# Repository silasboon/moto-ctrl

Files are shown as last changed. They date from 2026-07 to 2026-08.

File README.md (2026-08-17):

# MOTO-CTRL

An open-source programmable motorcycle control board — an alternative to the
Motogadget m.Unit Blue. 12 switched outputs, 8 handlebar button inputs, BLE
phone-as-key immobilizer, and a companion mobile app, built around an
ESP32-S3. Open design, sold assembled by the project — Speeduino-style.

**MOTO-CTRL is feature-complete for its first release.** The firmware core,
BLE protocol, a WebSocket simulator with a browser debug GUI and QEMU boot
validation, the companion app (pairing, dashboard, output and button
configuration), the phone-as-key immobilizer, diagnostics (current sensing,
learnable fault thresholds, low-voltage cutoff), turn signals/hazard/brake
flasher with PWM dimming, and OTA firmware updates (signed images over BLE
with A/B partitions, a persisted security/safety event log, and a
forward-tolerant config format) are all implemented and covered by the
app's Firmware Update and Event Log screens and the maintainer
release-signing tool (`tools/sign-firmware.py`). Verified against the
simulator and host unit tests, and on real hardware: v1 boards exist, the
firmware runs on them, the app drives them over BLE, and the bench
checklist in [`docs/HARDWARE_TESTING.md`](docs/HARDWARE_TESTING.md) has
been worked through. See [`docs/PROTOCOL.md`](docs/PROTOCOL.md) for the
wire protocol, [`docs/TESTING.md`](docs/TESTING.md) for how all of this is
tested, and [`docs/WIRING.md`](docs/WIRING.md) /
[`docs/FLASHING.md`](docs/FLASHING.md) / [`docs/FAQ.md`](docs/FAQ.md) for
installing and flashing a board.

## Before anything else

- [`DISCLAIMER.md`](DISCLAIMER.md) — this is not a certified automotive
  safety device. Read it before wiring anything to a motorcycle.
- [`LICENSE-NOTE.md`](LICENSE-NOTE.md) — plain-English licensing summary
  (personal use/builds OK, selling boards or derivatives is not).
- Contributing? See [`CONTRIBUTING.md`](CONTRIBUTING.md) for the ground
  rules before opening a PR.

## Repository layout

```
moto-ctrl/
├── firmware/          ESP-IDF (C, FreeRTOS, NimBLE) firmware + host simulator
├── app/                bare React Native + TypeScript companion app
├── hardware/           schematic, PCB design, gerbers, BOM (per hardware revision)
│   ├── PINOUT.md        firmware ↔ hardware pin contract — read before touching pins
│   └── releases/         e.g. releases/v1/, matching git tags
├── enclosure/          STL/STEP files (FDM ASA prototype, MJF PA12 production)
├── docs/               wiring guide, flashing guide, protocol spec, FAQ, hardware bench checklist
├── tools/              version bump, OTA release signing, native app bootstrap
├── Makefile            build / test / release automation (make help)
└── .github/workflows/  CI: firmware build, app build, tests
```

## Building and testing

Everything except an on-target firmware build works with no hardware and no
ESP-IDF toolchain — the host simulator stands in for the board.

```sh
make test          # host ctest + sim integration tests + app typecheck/lint/jest
make help          # all targets
```

To work on the firmware and drive it by hand, build the host simulator and
open the browser debug console against it:

```sh
cd firmware/sim
cmake -S . -B build && cmake --build build
./build/moto_ctrl_sim 8010          # ws://127.0.0.1:8010
```

Then open `firmware/sim/gui/index.html` in a browser and click Connect —
live output state, per-channel current/faults, virtual handlebar buttons,
fault injection, and scenario record/replay. This is the primary day-to-day
development tool; see [`docs/TESTING.md`](docs/TESTING.md).

Building the real firmware needs the ESP-IDF toolchain
([`firmware/README.md`](firmware/README.md)); running the app on a device
needs Xcode or the Android SDK ([`app/NATIVE_SETUP.md`](app/NATIVE_SETUP.md)).
Flashing is UART0-only with a manual BOOT/EN sequence — see
[`docs/FLASHING.md`](docs/FLASHING.md).

Firmware releases are signed: `make release v=X.Y.Z` bumps the version,
builds, and signs a `.mcota` bundle; `make publish v=X.Y.Z` also tags and
creates the GitHub Release the app's update check reads. The signing key
lives outside this repo — see [`tools/README.md`](tools/README.md).

## Hardware

MCU: ESP32-S3-WROOM-1-N4 (4MB flash, no PSRAM), BLE 5. 12 outputs via 6×
Infineon BTS7008-2EPA high-side PROFETs with current sense and diagnostics.
8 active-low handlebar button inputs. 12V motorcycle power, LiFePO4-compatible.
UART0-only programming (no USB). See [`hardware/PINOUT.md`](hardware/PINOUT.md)
for the full pin contract.

## Software stack

- **Firmware:** ESP-IDF + NimBLE, C, FreeRTOS. A host simulator
  (`firmware/sim/`) builds the core state machine and protocol on
  Linux/macOS against a fake BLE transport, so the app and CI don't need
  real hardware.
- **App:** bare React Native + TypeScript (no Expo), BLE via
  `react-native-ble-plx`. Offline-first, zero cloud dependency, no accounts.

## Safety-critical behavior

MOTO-CTRL switches lighting, signaling, ignition, and starter circuits on a
moving vehicle. A handful of safety rules override every feature request
and are not up for debate in a PR: a BLE disconnect, app crash, or phone
absence never changes output state; the immobilizer can only lock while
the bike is stopped and off; every configured unlock method works at once,
and at least one non-phone method — the button cheat-code or an
ignition-switch input — must be configured before the immobilizer can be
enabled, so a dead phone can't strand you; phone-as-key uses bonded,
cryptographically signed challenge-response, never a bare MAC
address; the brake light is always on whenever the brake is pulled,
attention-flash pattern or not; the starter is never remotely triggerable
and is inhibited while the engine is already running; and low-battery
protection never disables the unlock path. See
[`CONTRIBUTING.md`](CONTRIBUTING.md) before proposing a change to lock,
output, or auth behavior, and [`DISCLAIMER.md`](DISCLAIMER.md) for what
this does and doesn't mean for your own liability.

## License

- Code (`firmware/`, `app/`, `tools/`): [PolyForm Noncommercial 1.0.0](LICENSE-CODE)
- Hardware & docs (`hardware/`, `enclosure/`, `docs/`): [CC BY-NC-SA 4.0](LICENSE-HARDWARE)
- Summary: [`LICENSE-NOTE.md`](LICENSE-NOTE.md)

## Contributing

See [`CONTRIBUTING.md`](CONTRIBUTING.md).

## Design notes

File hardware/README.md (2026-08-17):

# hardware/

Hardware design sources for MOTO-CTRL, licensed under CC BY-NC-SA 4.0 (see
[`../LICENSE-HARDWARE`](../LICENSE-HARDWARE) and
[`../LICENSE-NOTE.md`](../LICENSE-NOTE.md)).

- [`PINOUT.md`](PINOUT.md) — the firmware ↔ hardware contract: every GPIO
  assignment on the current board revision. This is the single source of
  truth firmware pin definitions must be generated from (see
  [`../CONTRIBUTING.md`](../CONTRIBUTING.md)).
- `releases/<rev>/` — per-hardware-revision design exports (EasyEDA Pro
  project source — `.epro`/`.epro2` depending on version, from `File ->
  Save As -> Save As (Local)`, which archives schematic + PCB + the device
  libraries and footprints actually used, whether the project itself lives
  in EasyEDA's cloud or locally — plus schematic PDF, `gerbers/`, `bom/`,
  `pnp/`), tagged in git to match the revision. `PINOUT.md` documents the
  current/latest revision; each `releases/<rev>/` snapshot is what actually
  shipped for that revision.

## Revisions

| Revision | Status | Notes |
|---|---|---|
| v1 ("Integrated V2") | current | First released hardware revision — "Integrated V2" is the schematic's own internal board name, from before this was a public project; the repo's revision numbering starts fresh at v1. See `PINOUT.md`, dated 2026-07-18. Design files are in [`releases/v1/`](releases/v1/). |

Only one PROFET may have DEN high at a time, GPIO3/GPIO46 are strapping
pins used safely by design (see `PINOUT.md`'s warning) — if you're revising
the hardware, re-read `PINOUT.md` in full before changing pin assignments,
since firmware depends on it directly.

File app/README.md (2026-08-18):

# app/

MOTO-CTRL companion app — bare React Native + TypeScript (no Expo), offline
first, zero cloud dependency, no accounts (see
[`CONTRIBUTING.md`](../CONTRIBUTING.md) for the full rule and its one
narrow exception). BLE/key logic must go through the `Transport` interface.

## Layout

- `src/transport/` — the `Transport` interface (channel-aware: `send`/
  `onMessage` take the logical channel explicitly, since BLE and the
  WebSocket sim frame it differently — see `docs/PROTOCOL.md` §1) and its
  two implementations:
  - `SimTransport` — talks to `firmware/sim/` over WebSocket. Used for all
    local dev and CI, so neither needs a board attached.
  - `BlePlxTransport` — real hardware, via `react-native-ble-plx`. Verified
    against a v1 board; re-check it per release with
    `docs/HARDWARE_TESTING.md`.
- `src/protocol/` — the real wire protocol (`docs/PROTOCOL.md`), transport-
  agnostic: `constants.ts` (opcodes/channels, mirrors `mc_protocol.h` by
  hand — deliberately excludes the simulator-only debug channel), `frames.ts`
  (byte/base64/utf8 helpers), `types.ts` (status + config JSON shapes), and
  `MotoClient.ts` — the high-level async client (auth, status polling,
  commands, config read/write) everything else is built on.
- `src/identity/KeyStore.ts` — persists this phone's Ed25519 identity
  (AsyncStorage, not platform secure storage — see the file's own header
  comment for why and `docs/TESTING.md` for when that might change) and the
  last-paired device.
- `src/update/updateCheck.ts` — the app's one permitted network call
  (fetching/verifying a firmware update manifest and bundle — see
  `docs/PROTOCOL.md` §10.5 and `CONTRIBUTING.md`'s "No cloud, no telemetry,
  no accounts" section), kept in its own module deliberately separate from
  `src/protocol/` (BLE/simulator wire protocol only).
- `src/screens/` — `PairingScreen` finds and authenticates a board.
  `DashboardScreen` ("Ride") is the landing screen: status, output control,
  a quick lock/unlock action, a battery/fault/low-voltage-cutoff indicator,
  and a Hazard button. Everything else sits one tap away behind
  `SettingsScreen`, the hub reached from Ride's settings button:
  - `OutputsScreen` — name each of the 12 channels, pick its behaviour
    (toggle, momentary, blink, flasher) and PWM dimming, and set the role
    flags that carry real firmware behaviour (`essential`, `is_ignition`,
    `is_starter`, `is_brake`).
  - `ButtonsScreen` — name the 8 inputs and bind single/double/hold presses
    and chords to output channels or turn/hazard actions, with an
    identify-by-pressing flow (`INPUT_LEARN`).
  - `BoardScreen` — settings about the board itself (currently its name).
  - `KeysScreen`, `LockScreen` (immobilizer enable/methods, cheat-code
    set/clear/test, ownership transfer).
  - `DiagnosticsScreen` — live per-channel current + fault, learnable
    open-load/overcurrent thresholds, low-voltage-cutoff and
    engine-running voltage config, board calibration, and a live BLE
    signal-strength (RSSI) readout — phone-side, read straight from the
    radio via `Transport.readRssi()`, for bench-testing how far phone-as-key
    reaches with the board mounted on the bike. Advisory only: nothing in
    the unlock path reads this value.
  - `FirmwareUpdateScreen` (checks for/downloads/transfers a signed OTA
    update, then applies it on request), `EventLogScreen` (read-only viewer
    for the device's persisted security/safety event log), and
    `BoardInfoCard` (firmware version + uptime, shown atop Settings).

  Screens are switched via local state in `App.tsx` — no navigation library
  (see `App.tsx`'s header comment for why). Leaving a screen with unsaved
  edits routes through `src/ui/NavGuard.tsx`, so an edge-swipe back gets the
  same confirmation the screen's own Back chevron does.
- `ios/`, `android/` — the committed bare-RN native projects (bundle ID
  `com.motoctrl.app`, BLE permissions configured). See
  [`NATIVE_SETUP.md`](NATIVE_SETUP.md) to build or regenerate them.

## Status

Pairing, dashboard, output and button configuration, the lock/immobilizer
screen, diagnostics, turn-signal/hazard/brake-flasher/PWM control, firmware
updates, and the event log viewer are all implemented against
`SimTransport` and verified against a real `firmware/sim/` instance (see
Testing below), and `BlePlxTransport` has been exercised against a real
board over BLE.

The cheat-code is write-only from the app's perspective by design — the
device only ever reports whether one is set and how long it is (never the
sequence, never a hash); physical entry happens on the handlebar buttons,
not through this app.

Diagnostics thresholds/cutoff config go through dedicated `DIAG_GET_CONFIG`/
`DIAG_SET_CONFIG` wire ops (same pattern as lock config), not the generic
config JSON, even though they also ride it for export/import completeness
(`DeviceConfig.diagnostics`) — `DiagnosticsScreen` edits live values through
the dedicated ops. Board calibration is a separate, even-less-often-touched
set of ops (`DIAG_GET_CALIB`/`DIAG_SET_CALIB`) that never rides a config
export/import or gets cleared by ownership transfer, since it describes the
physical board, not the owner.

Flasher/PWM config (behaviour, duty, auto-cancel/blink/pulse timing,
brake-switch input) is different from both of the above: it rides the
generic config JSON exclusively (`OutputsScreen`, alongside name and role
flags — output config never had its own dedicated wire channel, unlike
lock/diagnostics). The one dedicated opcode here is `hazardPress()` — a
plain turn-signal toggle is still just `setOutput()` on a channel whose
`indicator` is set to left or right; mutual exclusion and the auto-cancel
timer are applied device-side, not by this app.

Known MVP simplifications, not gaps in a safety requirement:

- Enrolling a second phone is done by pasting its base64 public key (shown
  on its own Pairing screen) into the first phone's Keys screen — no QR/
  camera flow, to avoid pulling in a camera dependency for a one-off step.
- The phone's private key lives in AsyncStorage, not the iOS Keychain /
  Android Keystore — a deliberate initial simplification, not yet
  revisited.
- `MotoClient` polls status on an interval rather than relying on
  device-pushed notifications: real firmware only replies to an explicit
  `STATUS_GET` today (unlike the simulator's dev-convenience ticker).
- **Background BLE reconnect** (`src/ble/BoardSession.ts`) is what lets
  phone-as-key reconnect and unlock without the app open. It's a single
  always-running watch/connect/retry state machine, started unconditionally
  at boot (`index.js`, before `AppRegistry.registerComponent`) rather than
  from any screen, so it's already running by the time a background-relaunch
  needs it. `src/ble/bleManager.ts` constructs the shared `BleManager` with
  `restoreStateIdentifier`/`restoreStateFunction` (iOS CoreBluetooth state
  restoration; `UIBackgroundModes` → `bluetooth-central` in Info.plist is
  the corresponding capability declaration) so a fully-terminated app can
  pick a reconnecting peripheral back up. `src/ble/nativeBleWatchService.ts`
  bridges to `BleWatchService` (Android-only native module,
  `android/app/src/main/java/com/motoctrl/app/ble/`) — a foreground service
  with a persistent low-priority notification, since Android freezes or
  kills a backgrounded process with no foreground service, which would
  otherwise silently stop the watcher. `PairingScreen`'s own scan/tap flow
  still exists for pairing a new board or an impatient manual reconnect
  (`BoardSession.connectManually()`, sharing an in-flight guard with the
  watcher so the two can never race a double-connect); App.tsx subscribes to
  `BoardSession` directly rather than owning connection state itself.
  Compiles and typechecks clean on both platforms (`./gradlew assembleDebug`,
  `xcodebuild … -sdk iphonesimulator`) and the state machine has unit
  coverage (`src/__tests__/BoardSession.test.ts`), but **has not been
  bench-verified on real hardware** — background reconnect is exactly the
  kind of behavior that only really proves itself on a physical phone across
  a real suspend/kill/relaunch cycle. See `docs/HARDWARE_TESTING.md` §7.

## Development

```sh
npm install
npm run typecheck
npm run lint
npm test
```

`npm test` includes a live integration suite
(`src/__tests__/sim.itest.test.js`) that spawns a real `firmware/sim/`
instance and drives it through `SimTransport` + `MotoClient` — build the sim
first, or it skips gracefully:

```sh
cd ../firmware/sim && cmake -S . -B build && cmake --build build
```

Running on a device (`npm run ios` / `npm run android`) needs Xcode or the
Android SDK — see [`NATIVE_SETUP.md`](NATIVE_SETUP.md). BLE needs a physical
device; it does not work on the iOS Simulator or a stock Android emulator.

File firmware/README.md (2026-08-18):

# firmware/

ESP-IDF (C, FreeRTOS, NimBLE) firmware for the MOTO-CTRL board
(ESP32-S3-WROOM-1-N4). See [`CONTRIBUTING.md`](../CONTRIBUTING.md) for the
safety requirements and pin-config rule that govern everything in this
directory, and [`hardware/PINOUT.md`](../hardware/PINOUT.md) for the pin
contract.

## Layout

- `components/core/` — the portable core: state machines + protocol + auth,
  plain C99 with no ESP-IDF/FreeRTOS dependency, built by both the on-target
  component and `sim/` from the same sources.
  - `mc_output` (12-channel output engine; on/off, PWM dimming, and
    turn/brake flasher patterns — see below), `mc_input`
    (debounce, short/long/double press, chord + sequence combos),
    `mc_config` (versioned config blob + migration), `mc_persist`
    (debounced-write scheduler for NVS wear), `mc_power` (parked/idle power
    policy — decides tick rate, light sleep and advertising class).
  - `mc_crypto` (Ed25519 verify/sign + CSPRNG), `mc_keystore` (enrolled
    public keys), `mc_status` (status snapshot), `mc_config_json`
    (config ↔ JSON), `mc_session` (the transport-agnostic protocol + auth
    engine), `mc_protocol.h` (wire constants).
  - `vendor/` — TweetNaCl (Ed25519, public domain) + cJSON (MIT), unmodified.
- `components/board_config/` — the single source of GPIO pin definitions,
  generated from `hardware/PINOUT.md`, plus `board_config_early_init()`
  (GPIO3/GPIO46 strapping-pin safety). No other file may hardcode a GPIO
  number.
- `main/` — `app_main` and the ESP-IDF-specific glue: GPIO HALs
  (`output_hal_gpio` — plain digital plus lazily-attached LEDC PWM for
  opt-in dimming; `input_hal_gpio`), the current-sense/battery ADC HAL
  (`diag_hal` — DSEL/DEN mux sequencing, `hardware/PINOUT.md`), NVS stores
  (`nvs_config_hal`, `nvs_keystore_hal`,
  `nvs_lock_hal`, `nvs_calib_hal`), the physical factory-reset flow
  (`factory_reset.c`, BOOT-hold), `power_hal` (applies `mc_power`'s profile
  via `esp_pm` locks), `watchdog`, and `ble/` — the NimBLE GATT
  server (`gatt_svr.c`), LE Secure Connections bonding + advertising
  (`ble_app.c`), and UUIDs (`ble_uuids.h`), all wiring the BLE transport to
  `mc_session`.
- `sim/` — a standalone host (Linux/macOS) CMake project that builds
  `components/core/` behind a self-contained WebSocket "fake BLE" server
  (`src/ws_server.c`), plus C unit tests (`sim/tests/`) and Node integration
  tests (`sim/itest/`), so the app and CI run with no hardware. Independent
  of the ESP-IDF build.
  - `sim/src/sim_debug.c` + `sim_nvs.c` + `sim_protocol.h` — the sim-only
    debug/fault-injection channel (fake battery/current/fault, forced
    disconnect/reboot/NVS-corruption, event log) and fake NVS blob store
    that back it. Never part of the real protocol — see `docs/TESTING.md`.
  - `sim/gui/` — a static browser debug console (`index.html`/`app.js`, no
    build step) that drives the sim over WebSocket: live output state +
    real per-channel current/fault, a Hazard button, virtual buttons,
    auth/key management, lock/immobilizer config, diagnostics
    thresholds/calibration, config read/write (mode/duty/flasher-timing
    editing lives here, not as dedicated Outputs-panel widgets — see
    docs/TESTING.md), OTA transfer controls, an event log viewer, and
    scenario record/replay. The primary day-to-day dev tool for the app and
    firmware alike.
- `partitions.csv` / `sdkconfig.defaults` — 4MB flash, OTA A/B partitions
  with rollback, NimBLE-only Bluetooth (bonds persisted to NVS), no PSRAM,
  no WiFi, and the power-management options `mc_power` depends on (DFS +
  automatic light sleep, BLE controller modem sleep on the main crystal).

## Building the firmware (on-target)

Requires the [ESP-IDF](https://docs.espressif.com/projects/esp-idf/en/stable/esp32s3/get-started/index.html)
toolchain (latest stable), targeting `esp32s3`:

```sh
. $IDF_PATH/export.sh
cd firmware
idf.py set-target esp32s3
idf.py build
```

Flashing uses UART0 only (3-pin TX/RX/GND header, no USB, no auto-reset) —
see [`docs/FLASHING.md`](../docs/FLASHING.md) for the manual BOOT/EN sequence.

## Building the host simulator

No ESP-IDF toolchain required — just CMake and a C compiler:

```sh
cd firmware/sim
cmake -S . -B build
cmake --build build
ctest --test-dir build            # C unit tests

# Integration tests (WebSocket protocol + C<->JS Ed25519 interop) need Node:
cd itest && npm ci && MOTO_SIM_BIN=../build/moto_ctrl_sim npm test
```

Run the simulator standalone for app/GUI development (default port 8010):

```sh
./firmware/sim/build/moto_ctrl_sim 8010   # ws://127.0.0.1:8010
```

Then open `firmware/sim/gui/index.html` in a browser and click Connect. See
[`docs/TESTING.md`](../docs/TESTING.md) for the full harness (debug
protocol, scenario record/replay, QEMU boot validation).

## Building under QEMU (boot validation only — not BLE)

```sh
. $IDF_PATH/export.sh
cd firmware
idf.py set-target esp32s3 && idf.py build
python "$IDF_PATH/tools/idf_tools.py" install qemu-xtensa
timeout 30 idf.py qemu
```

Validates boot sequence, NVS/config load, output restore, and watchdog init
on the real binary. Does **not** validate BLE — see
[`docs/TESTING.md`](../docs/TESTING.md) §5 before drawing any conclusion
about pairing/bonding/auth from a QEMU run.

## Status

The full feature set is implemented and tested:

- **BLE stack.** The transport-agnostic protocol + auth engine
  (`mc_session`): status, control, and config (chunked JSON) channels, with
  all state-changing operations gated behind an Ed25519 challenge-response
  (`mc_crypto` + `mc_keystore`). The device stores only public keys; nonces
  are single-use. NimBLE GATT server with LE Secure Connections bonding
  (bonds in NVS), advertising as `MOTO-CTRL`, per-connection sessions.
- **Pre-hardware validation harness.** A real `mc_input` engine runs inside
  the sim (10ms tick); a fake NVS blob store makes config/keystore/lock/
  calibration persistence — and its corruption — real and reloadable via a
  simulated reboot; the sim-only debug channel + browser GUI (`sim/gui/`);
  and QEMU boot validation, which boots the real cross-compiled binary and
  checks its boot-sequence log markers. QEMU is a local-only step — it is
  **not** part of CI, and it does not and cannot validate BLE. See
  `docs/TESTING.md` §5 before drawing conclusions from it.
- **Lock / immobilizer** (`mc_lock`, `docs/PROTOCOL.md` §11): the
  four-state FSM (DISABLED/UNLOCKED/PARKED/LOCKED), edge-triggered
  phone-as-key auto-unlock, a salted-hash button cheat-code with
  progressive wrong-entry backoff, ignition-switch mode, ownership
  transfer, and the physical BOOT-hold factory reset (`factory_reset.c`).
- **Diagnostics** (`mc_diag`, `docs/PROTOCOL.md` §12): round-robin
  per-channel current sensing over the shared PROFET IS line
  (`hardware/PINOUT.md`) with learnable open-load/overcurrent thresholds;
  `engine_running`, feeding the starter-protection and lock
  parked-detection guards — an unconditional ignition-off override (an
  assigned ignition channel that's off always means not-running) plus
  opt-in, off-by-default voltage-based detection (never assumed, since a
  booster pack looks identical to a running alternator); a low-voltage
  battery cutoff that
  suppresses non-essential outputs (`CONTRIBUTING.md` safety requirement
  #7) while leaving commanded/intent state untouched; and board calibration
  in its own NVS blob, excluded from config export/import and from factory
  reset (it describes the board, not the owner).
- **Flashers / PWM** (`mc_output`, `docs/PROTOCOL.md` §13): turn signals
  and hazard, with mutual exclusion and an auto-cancel timer embedded
  directly in `mc_output_set()` (so any caller — a handlebar button, or the
  `HAZARD_PRESS` wire op — gets correct behavior for free), a brake-flasher
  attention-pulse burst (opt-in, off by default per `CONTRIBUTING.md`
  safety requirement #5), and opt-in per-channel PWM dimming
  (lazily-attached LEDC on real hardware). Handlebar buttons bind to
  actions besides the cheat-code — each of `short_press_action[]`,
  `long_press_action[]` and `double_press_action[]` holds a per-button LIST
  of actions (turn-L/turn-R toggle, hazard press, or `256 + N` to toggle
  output channel N directly) — and a physical brake-lever/pedal switch input
  (`brake_switch_input`, read as a level, mirrors
  `starter_interlock_input`).
- **OTA + config migration + event log** (`mc_ota`, `mc_event_log`,
  `docs/PROTOCOL.md` §10/§15): signed firmware updates over BLE (A/B
  partitions, Ed25519 signature over a streamed SHA-512 digest so no PSRAM
  buffering is needed, safe-state gating on `engine_running`/low-voltage
  cutoff at both begin and reboot time) and a persisted, fixed-size ring
  buffer of security/safety events (lock transitions, key enroll/revoke/
  transfer, factory reset, cheat-code lockout, OTA begin/success/failure,
  low-voltage cutoff), readable over its own chunked wire op. Config
  migration needed no new code: `mc_config_json`'s already-tolerant parsing
  (missing fields default, unknown fields ignored) handles an older or
  newer-but-understood document without a separate binary migration path —
  only a future schema version this firmware doesn't understand is
  rejected outright. `tools/sign-firmware.py` generates the release keypair
  and signs images into `.mcota` bundles; the app has a Firmware Update
  screen and an Event Log viewer.
- Protocol spec: [`docs/PROTOCOL.md`](../docs/PROTOCOL.md).

Verified: host `ctest` (12 suites, including `test_ota.c`/
`test_event_log.c`), the Node integration suite (33 cases against a real
spawned sim, including a full signed OTA transfer, safe-state-gating
rejection, and event log read/since_seq coverage), and the app's own Jest
suite (116 cases across 11 files) — all pass. Beyond that, the firmware has
been built for the real `esp32s3` target, flashed to a board, and driven
over BLE from the app, and the bench checklist in
[`../docs/HARDWARE_TESTING.md`](../docs/HARDWARE_TESTING.md) has been worked
through against real hardware. Re-run that checklist per release rather than
treating it as settled — it is the only layer that covers real GPIO, real
current sensing, and real BLE.

**Parked power management** (`mc_power`, `power_hal`). The portable policy
picks one of three levels from the live device state — ACTIVE (10ms tick, no
sleep), IDLE (100ms, light sleep allowed), PARKED (250ms, light sleep, slow
BLE advertising) — and `power_hal` applies it via `esp_pm` locks and the
advertising interval. Light sleep rather than deep sleep is forced by the
hardware: deep-sleep GPIO wake needs an RTC-capable pin and BTN1-8 are on
GPIO35-42, outside the ESP32-S3's RTC domain (GPIO0-21). Light sleep also
keeps the radio up, so phone-as-key stays live on a parked bike. Buttons
wake the loop through a GPIO interrupt that notifies `app_task`, with the
250ms parked tick as a backstop if that notify is ever missed. Every
hold-awake gate (outputs driven, engine running, ignition live, OTA in
flight, a gesture in progress, factory-reset window open) pins ACTIVE and
refuses sleep — `test_power.c` covers each one. Not yet measured on a
bench: `docs/HARDWARE_TESTING.md` §1 is where the number gets recorded.

Two implementation notes worth knowing about:

- `firmware/sdkconfig.defaults` enables
  `CONFIG_BOOTLOADER_APP_ROLLBACK_ENABLE`, so every OTA-updated image boots
  in "pending verify" state and the bootloader would revert on the *next*
  reset unless the image confirms itself. `app_main()` calls
  `esp_ota_mark_app_valid_cancel_rollback()` as its last step, once every
  boot stage (config/output/lock restore, diagnostics, input, watchdog,
  BLE) has completed without crashing — see the comment at that call site,
  and `docs/HARDWARE_TESTING.md` §11 for the reset-after-OTA check.
- The physical factory reset is a 5-second arming window watched on the app
  tick (`factory_reset_init()` / `factory_reset_tick()`), not a sample at
  boot: holding BOOT through reset enters UART download mode, because BOOT
  is GPIO0 and its level at the strap instant selects the boot path, so
  `app_main()` would never run. The gesture is "apply power, then press and
  hold BOOT" — see `firmware/main/factory_reset.h`, `docs/FLASHING.md`'s
  Factory reset section, and `docs/HARDWARE_TESTING.md` §9.

The generic `combos[]` chord/sequence mechanism dispatches its own
`actions` list, orthogonal to the lock cheat-code and to the per-button
press bindings, which all consume short-press events independently of the
combo matcher. A matched *chord* additionally marks its member buttons so
their own bindings don't also fire (the press event is still delivered,
flagged `action_suppressed`, so the cheat-code can never be starved — see
`mc_input.h`). A matched *sequence* suppresses nothing, since its member
presses were already delivered before it completed.

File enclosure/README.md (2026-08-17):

# enclosure/

Enclosure design files for MOTO-CTRL, licensed under CC BY-NC-SA 4.0 (see
[`../LICENSE-HARDWARE`](../LICENSE-HARDWARE)).

- FDM ASA — prototype/hobbyist printing.
- MJF PA12 — production.

Two printed parts per revision — a base and a separate lid:

```
enclosure/
└── v1/
    ├── moto-ctrl-enclosure-v1.step   # base, source/editable
    ├── moto-ctrl-enclosure-v1.stl    # base, print-ready
    ├── moto-ctrl-lid-v1.step         # lid, source/editable
    └── moto-ctrl-lid-v1.stl          # lid, print-ready
```

Per-revision print settings and material notes (layer height, walls,
infill, orientation, supports, and what differs between the ASA prototype
and the MJF production part) are **not written up yet** — print the STLs
with sensible ASA defaults until they are.

Enclosure revisions should track hardware revisions in `hardware/releases/`
— an enclosure for board rev v1 assumes the connector/mounting layout of
`hardware/releases/v1/`.

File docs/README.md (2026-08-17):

# docs/

User- and protocol-facing documentation, licensed under CC BY-NC-SA 4.0 (see
[`../LICENSE-HARDWARE`](../LICENSE-HARDWARE)).

| Doc | Content |
|-----|---|
| [`PROTOCOL.md`](PROTOCOL.md) | BLE GATT layout: status/control/config/lock/diagnostics/flashers/OTA/event-log services + auth, documented for third-party clients |
| [`TESTING.md`](TESTING.md) | Test pyramid, sim debug GUI, sim-only debug protocol, scenario format, QEMU boot validation and its BLE-fidelity limits |
| [`WIRING.md`](WIRING.md) | Wiring guide for installing MOTO-CTRL on a motorcycle |
| [`FLASHING.md`](FLASHING.md) | UART0 flashing guide, manual BOOT/EN sequence (no USB, no auto-reset) |
| [`FAQ.md`](FAQ.md) | Frequently asked questions |
| [`HARDWARE_TESTING.md`](HARDWARE_TESTING.md) | Bench validation checklist — worked through on v1 hardware; re-run per release |

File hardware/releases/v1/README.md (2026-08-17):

# hardware/releases/v1/

Design export for hardware revision v1 ("Integrated V2" on the schematic
itself — that name predates this being a public project; the repo's own
revision numbering starts at v1) — the revision documented in
[`../../PINOUT.md`](../../PINOUT.md).

```
v1/
├── schematic.pdf
├── moto-ctrl-v1.epro2      # EasyEDA Pro project export (source) --
│                           # File -> Save As -> Save As (Local)
├── gerbers/                # Gerber RS-274X + Excellon drill, JLCPCB naming
├── bom/
└── pnp/
```

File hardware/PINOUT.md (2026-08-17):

# MOTO-CTRL Hardware Pinout — Board "Integrated V2" (schematic 2026-07-18)

This file is the firmware ↔ hardware contract. All pin definitions in firmware must
come from a single board-config header generated from this table. Source of truth:
`hardware/releases/v1/` schematic.

MCU: ESP32-S3-WROOM-1-N4. UART0 programming only (no USB — IO19/IO20 are
intentionally unconnected). Manual boot entry: hold BOOT (SW2, IO0) and pulse
RESET (SW1, EN).

## PROFET control (6× BTS7008-2EPA, U2–U7)

Each PROFET has two channels: IN0 → OUTx (odd), IN1 → OUTy (even).
All PROFET logic lines go through 4.7kΩ series resistors.

| Device | Signal | ESP32 GPIO | Drives |
|---|---|---|---|
| U2 | PROFET_IN1  | GPIO47 | OUT1 |
| U2 | PROFET_IN2  | GPIO14 | OUT2 |
| U2 | PROFET_DEN1 | GPIO21 | U2 diag en  |
| U3 | PROFET_IN3  | GPIO13 | OUT3 |
| U3 | PROFET_IN4  | GPIO11 | OUT4 |
| U3 | PROFET_DEN2 | GPIO12 | U3 diag en  |
| U4 | PROFET_IN5  | GPIO10 | OUT5 |
| U4 | PROFET_IN6  | GPIO3  ⚠ | OUT6 |
| U4 | PROFET_DEN3 | GPIO46 ⚠ | U4 diag en  |
| U5 | PROFET_IN7  | GPIO8 | OUT7 |
| U5 | PROFET_IN8  | GPIO17 | OUT8 |
| U5 | PROFET_DEN4 | GPIO18 | U5 diag en  |
| U6 | PROFET_IN9  | GPIO16 | OUT9 |
| U6 | PROFET_IN10 | GPIO7 | OUT10 |
| U6 | PROFET_DEN5 | GPIO15 | U6 diag en  |
| U7 | PROFET_IN11 | GPIO6 | OUT11 |
| U7 | PROFET_IN12 | GPIO4 | OUT12 |
| U7 | PROFET_DEN6 | GPIO5 | U7 diag en  |

Shared diagnostic lines:

| Signal | ESP32 GPIO | Notes |
|---|---|---|
| PROFET_DSEL  | GPIO48 | Channel select for IS mux, shared across U2–U7 |
| PROFET_IS | GPIO9 | ADC1_CH8. Sense: 2kΩ (R3) to GND, RC 2.2kΩ/1nF |

⚠ Strapping pins: GPIO3 (JTAG source) and GPIO46 (ROM log) are used as outputs to
PROFET IN6/DEN3. Both are pulled inactive by the PROFET input structure at boot and
the assignment is verified safe on this hardware — but firmware must never enable
internal pullups on these two pins before boot completes, and must drive them low
during early init.

## Diagnostics readout procedure

Only one PROFET may have DEN high at a time. To read a channel current:
set DSEL (0 = OUT-odd/IN0 channel, 1 = OUT-even/IN1 channel), raise that device's
DENx, settle, read ADC on GPIO9, lower DENx. Round-robin all 12 channels.
I_load ≈ (V_IS / 2000Ω) × kILIS (see BTS7008-2EPA datasheet; calibrate per board).

## Handlebar buttons (via CN2)

Active-low. Each input: 2.2kΩ series + 10kΩ pullup to 3V3 + 10nF to GND.

| Signal | ESP32 GPIO |
|---|---|
| BTN1 | GPIO35 |
| BTN2 | GPIO36 |
| BTN3 | GPIO37 |
| BTN4 | GPIO38 |
| BTN5 | GPIO39 |
| BTN6 | GPIO40 |
| BTN7 | GPIO41 |
| BTN8 | GPIO42 |

## Analog

| Signal | ESP32 GPIO | ADC channel | Notes |
|---|---|---|---|
| VSENSE_BAT | GPIO1 | ADC1_CH0 | 1MΩ/100kΩ divider, ratio 0.0909. Use 12dB attenuation. Filter cap C5 100nF. Calibrate offset/gain per board. |
| PROFET_IS  | GPIO9 | ADC1_CH8 | See diagnostics section |

## System / programming

| Function | Pin | Notes |
|---|---|---|
| UART TX | TXD0 (GPIO43) | 3-pin header H1: 1=TX, 2=RX, 3=GND (3.3V logic, no auto-reset) |
| UART RX | RXD0 (GPIO44) | |
| BOOT | GPIO0 (SW2) | Also usable at runtime as the factory-reset button (hold at power-on) |
| RESET | EN (SW1) | 10kΩ pullup + 1µF |

## Reserved / unconnected

| Pin | Status |
|---|---|
| GPIO2  | Spare, ADC1-capable, routed to no net. Reserved: NTC board temp / 5V monitor / aux analog. No driver yet. |
| GPIO19 | NC (USB D-; USB intentionally unused) |
| GPIO20 | NC (USB D+) |
| GPIO45 | NC (strapping, VDD_SPI — correct to leave unconnected) |

## External connectors

CN1 (KF142V-5.08-12P, output terminal): pin N = OUTN for N = 1…12.
CN2 (KF142V-5.08-8P, button input terminal): reverse order — pin N = BTN(9−N).
  Pin 1 = BTN8, pin 2 = BTN7, pin 3 = BTN6, pin 4 = BTN5,
  pin 5 = BTN4, pin 6 = BTN3, pin 7 = BTN2, pin 8 = BTN1.
  (Verified by the board designer against the layout.)
Power: 4× M3 ring-terminal pads (U11–U14) — main +12V and GND, dual feed.
LEDs: LED1–LED12 mirror OUT1–OUT12 (2.2kΩ from each OUT rail); LED13 = 3V3 power
  indicator (4.7kΩ, R40).

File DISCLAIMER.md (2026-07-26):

# Disclaimer

MOTO-CTRL is an open-source hobbyist project. Read this before you build, flash,
wire, or ride with it.

## Not a certified automotive device

MOTO-CTRL has **not** been certified, homologated, or approved by any regulatory
body (no ISO 26262 functional-safety certification, no DOT/ECE/UNECE type
approval, no CE/FCC/UKCA compliance testing beyond whatever informal checks the
maintainer chooses to publish). It is not a product built to automotive
functional-safety standards. Do not treat it as one.

## You assume all risk

By designing, building, flashing, wiring, installing, configuring, or riding a
motorcycle equipped with MOTO-CTRL, you accept full responsibility for:

- Verifying the wiring, fusing, and installation are correct for your specific
  motorcycle before riding it.
- Confirming your installation complies with the vehicle regulations in your
  jurisdiction (lighting, signaling, and electrical codes vary by country and
  state/province — this project does not track them for you).
- Any damage to your motorcycle, its electrical system, or other property arising
  from use, misuse, or malfunction of this hardware or software.
- Any injury to yourself or others arising from use, misuse, or malfunction of
  this hardware or software, including but not limited to failure of lighting,
  signaling, starting, or immobilizer functions.
- Testing thoroughly on a bench and in a controlled, stationary setting before
  ever riding with a new configuration or firmware version.

## No warranty

THE SOFTWARE, HARDWARE DESIGNS, AND DOCUMENTATION ARE PROVIDED "AS IS", WITHOUT
WARRANTY OF ANY KIND, EXPRESS OR IMPLIED, INCLUDING BUT NOT LIMITED TO THE
WARRANTIES OF MERCHANTABILITY, FITNESS FOR A PARTICULAR PURPOSE, AND
NONINFRINGEMENT. IN NO EVENT SHALL THE AUTHORS, CONTRIBUTORS, OR THE MOTO-CTRL
PROJECT BE LIABLE FOR ANY CLAIM, DAMAGES, OR OTHER LIABILITY ARISING FROM,
OUT OF, OR IN CONNECTION WITH THE SOFTWARE, HARDWARE, OR THE USE OR OTHER
DEALINGS IN THEM — INCLUDING DAMAGE TO YOUR VEHICLE, PERSONAL INJURY, OR DEATH.
See the "No Liability" section of [`LICENSE-CODE`](LICENSE-CODE) and the
liability/warranty disclaimers in [`LICENSE-HARDWARE`](LICENSE-HARDWARE) for the
legally binding terms.

## Safety-critical wiring

MOTO-CTRL switches your motorcycle's lighting, signaling, ignition, and starter
circuits. A wiring mistake, a misconfigured output, or a firmware bug in a
modified fork can cause loss of lights, loss of signaling, an immobilized bike,
or unintended starter engagement. Always:

- Keep the stock ignition kill switch and any stock immobilizer functional and
  accessible as a fallback unless you fully understand what you are removing.
- Fuse every output appropriately for the connected load.
- Bench-test a new build (power, outputs, inputs) before installing it on the bike.
- Re-verify safety-critical behavior (lights, brake light, starter interlock)
  after every firmware update, on the bench, before riding.

## Project scope

This disclaimer applies to the MOTO-CTRL software (`firmware/`, `app/`), hardware
designs (`hardware/`, `enclosure/`), and documentation (`docs/`) in this
repository, and to any board — self-built or purchased assembled from the
MOTO-CTRL project — running this software or a derivative of it.

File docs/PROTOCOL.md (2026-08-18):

# MOTO-CTRL BLE Protocol

This document specifies the MOTO-CTRL wire protocol well enough for a
third-party client to be built. It is the authoritative companion to the
implementation in `firmware/components/core/` (`mc_protocol.h`,
`mc_session.c`) and the GATT definitions in `firmware/main/ble/`. If code and
this document ever disagree, that is a bug — please report it.

> **Status:** the status, control, config, lock/immobilizer (§11),
> diagnostics (§12), flashers/PWM (§13), OTA (§10), and event log (§15)
> services are all implemented.

## 1. Transports

The same logical protocol runs over two transports:

- **BLE GATT** (real hardware). Each *channel* below is a GATT
  characteristic. A client writes a frame to a characteristic and receives
  responses as notifications on the same characteristic.
- **WebSocket** (the `firmware/sim/` host simulator, for development and CI
  with no hardware). Each message is a single binary WebSocket frame whose
  **first byte is the channel id**, followed by the frame bytes. The
  simulator listens on `ws://127.0.0.1:<port>` (default `8010`).

A "frame" is identical on both transports:

```
frame = opcode:u8  payload:bytes
```

On BLE the channel is implied by which characteristic carried the frame; on
WebSocket the channel is the leading byte. Everything after that — opcode and
payload — is the same. A worked reference client is
`firmware/sim/itest/moto-client.mjs`.

Multi-byte integers are **little-endian** unless stated otherwise.

## 2. GATT layout

Base UUID: `5a4f00XX-9b1e-4f8a-9c2d-1a2b3c4d5e6f`, where `XX` selects the
service or characteristic.

| Service (UUID `XX`) | Characteristic (UUID `XX`) | Channel id | Properties |
|---|---|---|---|
| Status `0x10` | Status `0x11` | `0` | Read, Write, Notify |
| Control `0x20` | Auth `0x21` | `1` | Write, Notify |
| Control `0x20` | Command `0x22` | `2` | Write, Notify |
| Config `0x30` | Config `0x31` | `3` | Write, Notify |
| OTA `0x40` | OTA `0x41` | `4` | Write, Notify |

**Advertising layout.** The primary advertising payload carries the flags and
the **Status service UUID** (`5a4f0010-…`); the **name** is in the scan
response. Discover boards by that service UUID, never by name: the name is
rider-configurable (`device_name`, §9) and defaults to `MOTO-CTRL` only until
somebody changes it, so a name match finds only boards nobody has renamed.

The two were the other way round before `schema_version` 8. The UUID moved
into the primary payload so a scanner can filter on it reliably, and the name
moved out so it has the room a 128-bit UUID left it without (about 10 bytes
of the 31).

Clients that will read config **must** negotiate an ATT MTU large enough to
carry a config chunk frame (see §7): the 128-byte chunk payload plus a 4-byte
chunk header, opcode, and ATT overhead — request an MTU of at least ~185.

Clients that will perform an OTA update should negotiate the largest MTU the
stack supports (BLE 5's practical ceiling is 512 bytes of ATT payload) — a
larger MTU means fewer `OTA_CHUNK` round trips for the same image. There is
no minimum: `OTA_CHUNK` accepts any chunk size that fits one write, down to a
single byte, at the cost of more round trips.

## 3. Pairing and session model

1. **BLE bonding.** The client pairs using **LE Secure Connections**
   (Just Works; bonding enabled). This encrypts the link and persists a bond.
   Link/bond alone grants **no** authority — see below.
2. **Application-layer authentication.** Every connection starts an
   unauthenticated *session*. Until the session is authenticated via the
   challenge-response (§5), the device permits only: reading status (§4),
   `AUTH` operations (§5), and *first-key* enrollment (§6). All
   state-changing operations (control, config write) are refused with
   `UNAUTHENTICATED`.
3. A session is per-connection. Disconnecting drops the authentication;
   reconnecting requires authenticating again.

MAC address is never trusted as identity (see `CONTRIBUTING.md`'s safety
requirement #4).

## 4. Result codes

`*_RESULT` payloads carry a one-byte result:

| Value | Name | Meaning |
|---|---|---|
| 0 | `OK` | success |
| 1 | `UNAUTHENTICATED` | session has not passed challenge-response |
| 2 | `BAD_REQUEST` | malformed or truncated payload |
| 3 | `REJECTED` | semantically refused (e.g. starter over BLE, invalid config) |
| 4 | `ENROLL_DENIED` | enrollment not permitted in the current state |
| 5 | `KEYSTORE_FULL` | no free key slot |
| 6 | `NOT_FOUND` | referenced key slot not present |
| 7 | `NOT_IMPLEMENTED` | unused (OTA is implemented); kept for wire stability |
| 8 | `INTERNAL` | device-side error (e.g. RNG failure) |

## 5. Status channel (`0`)

| Direction | Opcode | Payload |
|---|---|---|
| → device | `0x01` `STATUS_GET` | — |
| ← device | `0x81` `STATUS` | 16-byte snapshot (below) |

On BLE the status characteristic is also directly **readable** (ATT Read),
returning the same 16-byte snapshot without a write. Status is available to
unauthenticated sessions.

Snapshot layout (16 bytes, little-endian):

| Offset | Size | Field |
|---|---|---|
| 0 | 1 | firmware major |
| 1 | 1 | firmware minor |
| 2 | 1 | firmware patch |
| 3 | 1 | lock state (`0`=UNKNOWN,`1`=PARKED,`2`=LOCKED,`3`=UNLOCKED) — see §11 |
| 4 | 4 | uptime (ms) |
| 8 | 2 | battery (mV) — calibrated reading, §12 |
| 10 | 2 | output state mask — bit *c* set ⇒ channel *c* is **commanded** on (rider/app intent — see §12's note on why this is not the same as "actually driven") |
| 12 | 2 | output fault mask — bit *c* set ⇒ channel *c* has a real open-load/overcurrent fault, §12 |
| 14 | 1 | RSSI (dBm, signed) — `0` if unknown |
| 15 | 1 | bit 0: cheat-code entry is in backoff (§11.4); bit 1: low-voltage cutoff is active (§12); bit 2: hazards are running (§9); bits 3–7 reserved |

## 6. Auth channel (`1`)

### Challenge-response

| Direction | Opcode | Payload |
|---|---|---|
| → device | `0x01` `AUTH_BEGIN` | — |
| ← device | `0x81` `AUTH_CHALLENGE` | `nonce` (32 bytes) |
| → device | `0x02` `AUTH_RESPONSE` | `signature` (64 bytes) |
| ← device | `0x82` `AUTH_RESULT` | `result:u8` `slot:u8` |

The client signs, with its Ed25519 **private key**, the message:

```
auth_message = "moto-ctrl-auth-v1"  ‖  nonce            (17 + 32 = 49 bytes)
signature    = Ed25519_sign(private_key, auth_message)  (detached, 64 bytes)
```

The 17-byte ASCII prefix is domain separation; there is no trailing NUL. The
device verifies the detached signature against every enrolled public key; a
match authenticates the session and returns the matching key `slot`. The
nonce is single-use and freshly random per `AUTH_BEGIN`, so a captured
signature cannot be replayed on another session. On failure the session
returns to unauthenticated and a new `AUTH_BEGIN` (new nonce) is required.

Ed25519 here is standard (RFC 8032, SHA-512), interoperable with
`tweetnacl` / `tweetnacl-js` (`nacl.sign.keyPair`, `nacl.sign.detached`).

### Enrollment

| Direction | Opcode | Payload |
|---|---|---|
| → device | `0x10` `ENROLL` | `pubkey` (32 bytes) `label` (UTF-8, ≤23 bytes) |
| ← device | `0x90` `ENROLL_RESULT` | `result:u8` `slot:u8` |

Enrollment is permitted when **either** the keystore is empty
(trust-on-first-use for the first key on a fresh or factory-reset device)
**or** the session is already authenticated (an existing owner adding another
phone). Otherwise it returns `ENROLL_DENIED`. Up to 8 keys may be enrolled.
Enrolling an already-present public key updates its label (idempotent).

> This forward-reference (written before the immobilizer existed) anticipated
> adding physical-button confirmation for the unattended-bike case on top of
> this rule. The immobilizer's actual implemented scope turned out to be the
> lock state machine, cheat-code, and ignition-switch mode specifically —
> enrollment confirmation wasn't part of it, and the existing TOFU/
> authenticated-owner rule above is unchanged. Flagged as an open item
> rather than silently implemented or silently left inaccurate.

### Key management (authenticated)

| Direction | Opcode | Payload |
|---|---|---|
| → device | `0x11` `KEY_LIST` | — |
| ← device | `0x91` `KEY_LIST_RESULT` | `count:u8` then per key: `slot:u8` `label_len:u8` `label:bytes` |
| → device | `0x12` `KEY_REVOKE` | `slot:u8` |
| ← device | `0x92` `KEY_REVOKE_RESULT` | `result:u8` `slot:u8` |

Revoking a key removes its public key immediately. Wiping all keys (ownership
transfer) is done via factory reset or by revoking each key.

## 7. Command channel (`2`) — authenticated

| Direction | Opcode | Payload |
|---|---|---|
| → device | `0x01` `SET_OUTPUT` | `channel:u8` `on:u8` |
| ← device | `0x81` `COMMAND_RESULT` | `req_opcode:u8` `result:u8` |

`SET_OUTPUT` switches an output channel (0–11). It is refused with
`REJECTED` if the channel's assigned function is **starter** — the starter is
never triggerable over the wire (see `CONTRIBUTING.md`'s safety requirement
#6), only via the hardware button path. Unauthenticated sessions get
`UNAUTHENTICATED`.

For a channel whose assigned function is `turn_l`/`turn_r`, `SET_OUTPUT`
also applies turn-signal policy device-side — see §13.

## 8. Config channel (`3`) — authenticated

Config is exchanged as JSON (see §9), chunked because a full config exceeds a
single BLE notification.

### Read

| Direction | Opcode | Payload |
|---|---|---|
| → device | `0x01` `CONFIG_READ` | — |
| ← device | `0x81` `CONFIG_CHUNK` | `offset:u16` `total:u16` `data:bytes` |

The device streams `CONFIG_CHUNK` frames (≤128 data bytes each). The client
reassembles by `offset` until it has `total` bytes.

### Write

| Direction | Opcode | Payload |
|---|---|---|
| → device | `0x02` `CONFIG_WRITE_BEGIN` | `total:u16` |
| → device | `0x03` `CONFIG_WRITE_CHUNK` | `offset:u16` `data:bytes` |
| → device | `0x04` `CONFIG_WRITE_COMMIT` | — |
| ← device | `0x82` `CONFIG_WRITE_RESULT` | `result:u8` |

`WRITE_BEGIN` declares the total JSON length (≤4096; larger is
`BAD_REQUEST`). The client sends the JSON as `WRITE_CHUNK`s, then `COMMIT`.
On commit the device parses the JSON, validates it (e.g. at most one
ignition, at most one starter — otherwise `REJECTED`), applies the new
configuration, and persists it. **Live output states are preserved across a
config write** — importing a config never toggles outputs (see
`CONTRIBUTING.md`'s safety requirement #1). `WRITE_BEGIN`/`WRITE_CHUNK` are
acknowledged only on error; `COMMIT` always returns a result.

## 9. Config JSON

The interchange form of the configuration. Fields absent on import take their
defaults; unknown `function` strings map to `"none"`.

```json
{
  "schema_version": 9,
  "device_name": "",
  "outputs": {
    "channels": [
      { "name": "Low Beam", "behaviour": "toggle", "pwm_duty_pct": 100,
        "commanded_on": false, "essential": true, "is_ignition": false,
        "is_starter": false, "is_brake": false, "indicator": "none",
        "hazard_member": false, "on_with_ignition": false,
        "alternate_channel": -1 }
    ],
    "starter_interlock_input": -1,
    "brake_switch_input": -1,
    "turn_auto_cancel_ms": 30000,
    "turn_flash_period_ms": 700,
    "brake_flash_pulse_count": 3,
    "brake_flash_pulse_on_ms": 150,
    "brake_flash_pulse_off_ms": 50
  },
  "inputs": {
    "timing": { "debounce_ms": 20, "long_press_ms": 600, "double_press_gap_ms": 350 },
    "combos": [
      { "type": "sequence", "buttons": [0, 1, 0, 1], "window_ms": 5000, "actions": [42] }
    ],
    "short_press_action": [[], [256], [], [], [], [], [], []],
    "long_press_action": [[], [], [], [], [], [], [], []],
    "double_press_action": [[], [], [], [], [], [], [], []],
    "names": ["Left Bar Top", "", "", "", "", "", "", ""]
  },
  "diagnostics": {
    "channels": [
      { "open_load_ma": 50, "overcurrent_ma": 15000 }
    ],
    "lv_cutoff_mv": 11800,
    "lv_cutoff_hysteresis_mv": 300,
    "engine_run_mv": 13800,
    "engine_run_hysteresis_mv": 300,
    "engine_run_voltage_detection_enabled": false
  }
}
```

- `outputs.channels` has exactly 12 entries (channels 0–11).
- **`schema_version` 6 replaced `function` and `mode`** with a free-text
  `name`, a `behaviour`, and explicit role flags. The old function taxonomy
  (`headlight_hi`, `horn`, `aux`, …) is gone: it forced a rider to mislabel a
  channel to get the behaviour they wanted, and — the reason it had to go —
  it hid a safety property inside a label, since a channel was only protected
  from the low-voltage cutoff if it happened to be tagged as a headlight.

  A document without the new keys is v5-or-older and is migrated on parse
  (see below), so old configs keep working with no separate migration step.

- `name`: free text, ≤23 characters plus NUL. Cosmetic — no firmware logic
  keys off a name.
- `behaviour` ∈ `toggle, momentary, blink, flasher`. Unknown/absent maps to
  `toggle`.
  - `toggle` — latching on/off.
  - `momentary` — on only while its trigger is held. Driven by a **hold**
    binding, a **held chord**, or a maintained switch; a single or double tap
    will never fire one, because those are edge events with nothing to hold.
  - `blink` — flashes at `turn_flash_period_ms` while on.
  - `flasher` — an attention-pulse burst on switch-on, then solid.
- `pwm_duty_pct`: 1–100. Below 100 dims the channel whenever it is driven on.
  Now a **modifier** rather than a mode, so it composes with `toggle` and
  `momentary`; never applied to `blink`/`flasher`, which are full on/off by
  the PWM/flasher rule.
- **Role flags** — the only channel properties carrying safety logic:
  - `essential` — never switched off by the low-voltage cutoff.
    `is_ignition` and `is_brake` are treated as essential regardless, so a
    config that forgets to set it still cannot shed them.
  - `is_ignition` — the immobilizer's target, and how the lock knows the bike
    is running. At most one channel (validated).
  - `is_starter` — never commandable from the app, inhibited while the engine
    runs, force-dropped the instant it starts, and gated behind
    `starter_interlock_input`. At most one channel (validated).
  - `is_brake` — the brake light; target of the `brake_switch_input`
    pass-through.
  - `indicator` ∈ `none, left, right` — turn mutual exclusion and the
    auto-cancel timer apply **only** to these.
  - `hazard_member` — blinks together with the hazards. Anything may join (a
    DRL, an aux light) without becoming an indicator, so joining the group
    grants no mutual exclusion or auto-cancel. `HAZARD_PRESS` switches every
    member together, and is `REJECTED` only when the group is empty.

    **While the hazards are running, every member blinks regardless of its own
    `behaviour`**, all in one shared phase. A DRL set to `toggle` is therefore
    steady in normal use and flashes with the indicators during a hazard stop —
    which is the point of the group, and why the rider is not asked to set
    `behaviour: blink` on it (that would make it blink as a running light too).
    Hazard mode ends on the next `HAZARD_PRESS`, or as soon as any member is
    commanded individually — signalling a turn, or switching the DRL on by
    itself, means the rider is no longer running hazards.

    **Ending the hazards restores every member to the state it was in when
    they started**, rather than switching the group off. Hazards borrow the
    group; they don't own it. A DRL that was already lit is lit again
    afterwards — the rider asked for the hazards to stop, not for their
    running light to go out — and a member that was off stays off. When the
    hazards end because a member was commanded directly, that channel is
    exempt (it is being set explicitly) and the rest are restored, so
    signalling a turn out of a hazard stop releases the opposite indicator
    instead of leaving it latched on and blinking. An indicator restored to
    ON re-arms its auto-cancel window from that moment, so a signal
    interrupted by a hazard stop can't end up latched on for the rest of the
    ride.

    A press therefore keys on whether hazard mode is running, not on whether
    every member happens to be lit: with restoring in place a group can
    legitimately have channels on while the hazards are stopped.

    Whether the hazards are running is reported on the status wire (byte 15
    bit 2), **not** inferable from `output_state_mask`: members blink, so that
    mask alternates several times a second and cannot distinguish running
    hazards from stopped ones. A client showing a hazard button needs the bit
    to label it correctly.

  - `on_with_ignition` (`schema_version` 7) — the channel switches on when the
    ignition channel switches on: what a key turned to `"on"` does on a stock
    bike. DRLs, running lights, an instrument cluster.

    **This flag governs switching ON only.** Switching the ignition OFF puts
    *every* channel out, flagged or not. A key that killed only the circuits
    it had lit, and left whatever the rider had switched on by hand still
    burning, would not be a key — and is a good way to find a flat battery.
    Hazard mode ends with it, so the status wire never reports running hazards
    over a dark group. Hazards can still be started with the ignition off,
    which is the point of a hazard switch on a parked bike.

    **Edge-triggered, not held.** The rider may still switch a flagged channel
    off while the ignition stays live, and it stays off until the next
    ignition cycle. A held assertion would mean a DRL could not be turned off
    without killing the ignition. Re-commanding an already-on ignition is not
    an edge and re-lights nothing.

    Restoring persisted state at boot does **not** fire this — it is not an
    edge, and synthesising one would light channels the rider had switched off
    before parking, contradicting the guarantee that boot replays exactly what
    was last commanded. An ignition command that is refused (immobilizer)
    likewise lights nothing, so this can never be a way around the lock.

  - `alternate_channel` (`schema_version` 7) — index of the channel this one
    alternates with (hi/lo beam, two DRL colours), or `-1` for none.

    **Must be reciprocal**: if `A` names `B`, `B` must name `A`. A config
    where it isn't is rejected whole (`MC_OUT_CFG_BAD_ALTERNATE`), because a
    one-way link is worse than none — switching `A` on would put `B` out, but
    switching `B` on would leave `A` lit, i.e. both beams burning. An
    `alternate_channel` that is out of range or points at itself is parsed as
    `-1` rather than failing the document, since a stray index is far more
    likely to be a truncated or hand-edited file than an intent.

    Lighting either member puts the other out, wherever the command came from
    — app, button binding, or brake pass-through — because the rule lives in
    the same place as turn mutual exclusion and so cannot be bypassed by
    adding a caller. A pair is **at most one on**, not exactly one: a direct
    command may still turn both off, so a rider can black out an aux pair from
    the app. It is only the `512 + N` binding (§9) that never lands on off.

    Both members of a pair carrying `on_with_ignition` is rejected
    (`MC_OUT_CFG_ALTERNATE_BOTH_IGNITION`) — they would fight over which one
    the ignition lights.

  **Migration from `schema_version` ≤ 5.** When the v6 keys are absent, roles
  are derived from the legacy `function` and behaviour from the legacy `mode`
  (plus v5's `momentary` bool):

  | legacy `function` | becomes |
  |---|---|
  | `ignition` | `is_ignition` + `essential` |
  | `brake` | `is_brake` + `essential` |
  | `headlight_hi` / `headlight_lo` | `essential` |
  | `turn_l` / `turn_r` | `indicator` + `hazard_member` |
  | `starter` | `is_starter` |
  | `horn` / `aux` / `none` | nothing — they never carried logic |

  | legacy `mode` | becomes |
  |---|---|
  | `on`, `pwm`, `off` | `toggle` (`pwm` survives as `pwm_duty_pct`) |
  | `flash_turn` | `blink` |
  | `flash_brake` | `flasher` |

- `starter_interlock_input` is an input index (0–7) or `-1` for none.
- `brake_switch_input`: an input index (0–7) or `-1` for none — see §13.
- `turn_auto_cancel_ms`, `turn_flash_period_ms`, `brake_flash_pulse_count`,
  `brake_flash_pulse_on_ms`, `brake_flash_pulse_off_ms`: see §13.
- `combos[].type` ∈ `chord, sequence`; `buttons` are input indices (0–7).
- **Action ids** (`short_press_action[]`, `long_press_action[]`,
  `double_press_action[]`, `combos[].action_id`) are `uint16`. All four
  binding paths accept the same vocabulary and are dispatched identically:

  | id | meaning |
  |---|---|
  | `0` | unbound |
  | `1` | toggle the channel whose `function` is `turn_l` |
  | `2` | toggle the channel whose `function` is `turn_r` |
  | `3` | toggle hazards (both turn channels) |
  | `256 + N` | toggle output channel `N` directly, `0 ≤ N < 12` |
  | `512 + N` | step the alternating pair channel `N` belongs to, `0 ≤ N < 12` |

  Ids `1`–`3` resolve by `function` and so depend on a channel being assigned
  that function; `256 + N` addresses a channel directly and always works,
  which is what a "bind this button to that output" UI should emit. All 12
  outputs are electrically identical, so direct addressing is the general
  case and `1`–`3` exist only because turn/hazard carry flasher-pattern
  behaviour beyond a plain toggle.

  `512 + N` (`schema_version` 7) drives an alternating pair: whichever member
  is lit, light the other; from cold, light `N` itself. **It never lands on
  both-off** — a headlight pair must not be switchable dark by a mistimed tap
  at night. Turning a pair off entirely is still possible, just not through
  this binding: it takes a direct command at the channel (`256 + N`, or the
  app). The id is `REJECTED`/ignored if channel `N` has no
  `alternate_channel`.

  A second reserved range rather than a flag on `256 + N`, so an older
  firmware that doesn't know the id ignores the binding outright instead of
  misreading it as a plain toggle and leaving both beams switchable off.

  An unrecognised id is ignored, not an import error — a config written by a
  newer firmware stays loadable (§ tolerant-parse rule above).

  **Each binding is a list, not a single id** (`schema_version` 4): one
  trigger may switch up to 4 outputs, applied left to right. So
  `short_press_action` is an array of 8 arrays, indexed by button, and a
  combo carries `actions` rather than `action_id`. An empty list means
  unbound. `0` is never a valid list entry — it is the "unbound" sentinel and
  is dropped on import.

  For compatibility, the parser also accepts the `schema_version` 3 spelling
  of both — a bare number instead of an array, and `action_id` instead of
  `actions` — treating a non-zero value as a one-element list. That is the
  entire v3 → v4 migration; there is no separate migration pass.

- `inputs.names` (added at `schema_version` 4) is 8 strings, indexed by
  input, truncated to 23 characters plus NUL. Purely cosmetic: nothing in the
  firmware dispatches on a button name. Empty means unnamed, and a client
  should fall back to "Button N".
- A matched **chord** suppresses its member buttons' own single-press
  bindings, so binding "L+R together" to hazards does not also fire L's and
  R's individual bindings. The press is still reported with
  `action_suppressed` set (see `INPUT_EVENT` below) — it is only the *action*
  that is skipped, never the press itself, because the unlock cheat-code is
  fed by those presses and must never become unreachable. A matched
  **sequence** does not suppress anything, since its member presses were
  already delivered before the sequence completed.
- At most `8` chord + sequence definitions combined (`MC_COMBO_MAX_DEFS`).
  A known, deliberate limit — see `mc_types.h`.

  Every binding is applied with source `LOCAL`, so it is still subject to the
  immobilizer, the starter engine-running/interlock guards, and turn mutual
  exclusion. A binding cannot switch a channel the COMMAND channel could not.
  In particular, binding a button to a `starter` channel is permitted (that is
  the hardware-button path) while the COMMAND channel remains blocked from it.
- `diagnostics.channels` has exactly 12 entries (channels 0–11) — per-channel
  open-load/overcurrent thresholds (§12), added at `schema_version` 2.
  **Board calibration is deliberately not here** — it has its own dedicated
  ops (§12) and never rides a config export/import, since it describes one
  physical board's analog sense lines, not a portable setting.
- `diagnostics.engine_run_voltage_detection_enabled` (`schema_version` 9,
  default `false`) opts into voltage-based `engine_running` detection —
  see §12.2. Absent from any pre-9 document, and `false` is exactly what
  such a document meant.
- `device_name` (`schema_version` 8) is the rider's name for the board — a
  nickname or bike model — up to 23 characters plus a NUL. **Empty means the
  factory default, `MOTO-CTRL`**, stored empty rather than as the literal so a
  board that was never renamed stays distinguishable from one deliberately
  named `MOTO-CTRL`; that is what lets `TRANSFER_OWNERSHIP` (§11.6) reset it.
  An over-long name is truncated rather than rejected, like channel and button
  names.

  **Discovery does not use it.** Because the name is now arbitrary, a client
  must identify a board by the status service UUID in its primary advertising
  payload (§2), never by matching the name — a name match would find only
  boards nobody has renamed. The name moved to the scan response when this
  landed, and the service UUID moved the other way, precisely so the stable
  identifier is the one a scanner can filter on.

  Changing it republishes the GAP device name and rebuilds the advertisement.
  Phones cache advertised names, so a client may keep showing the old one
  until it next discovers the board.

- `schema_version` is 8 (4 added input action lists + button names, 5 added
  per-channel `momentary`, 6 replaced `function`/`mode` with `behaviour` +
  role flags and folded `momentary` into it, 7 added `on_with_ignition` and
  `alternate_channel`, 8 added `device_name`).

  **7 needs no migration pass.** Both keys are absent from every earlier
  document, and their defaults (`false`, `-1`) are exactly what those
  documents meant: nothing came on with the ignition, and no channel had a
  partner. Tolerant parse leaves the defaults in place.

## 10. OTA channel (`4`) — authenticated

Firmware update over A/B partitions (`firmware/partitions.csv`'s `ota_0`/
`ota_1`), implemented in `mc_ota.c` and driven from `mc_session.c`. Every op
below requires an authenticated session, same as the COMMAND/CONFIG channels
— an unauthenticated frame gets `0x8F` `OTA_RESULT` with `UNAUTHENTICATED`
and no other effect.

| Direction | Opcode | Payload |
|---|---|---|
| → device | `0x01` `OTA_BEGIN` | `image_size:u32le` `sha512:u8[64]` `signature:u8[64]` (132 bytes) |
| → device | `0x02` `OTA_CHUNK` | `offset:u32le` `data:bytes` |
| → device | `0x03` `OTA_COMMIT` | — |
| → device | `0x04` `OTA_ABORT` | — |
| → device | `0x05` `OTA_REBOOT` | — |
| → device | `0x06` `OTA_STATUS` | — |
| ← device | `0x86` `OTA_STATUS_RESULT` | `result:1` `state:1` `bytes_received:u32le` `image_size:u32le` (10 bytes) |
| ← device | `0x8F` `OTA_RESULT` | `result:1` — reply for BEGIN/CHUNK/COMMIT/ABORT/REBOOT |

### 10.1 State machine

Four states (`mc_ota_state_t`), reported in `OTA_STATUS_RESULT`'s `state`
byte:

```
IDLE ──OTA_BEGIN(ok)──► RECEIVING ──OTA_COMMIT(ok)──► COMMITTED ──OTA_REBOOT(ok)──► (device reboots)
  ▲                         │                              │
  │                         │ any failure                  │ any failure
  └────── OTA_ABORT ────────┴──────────────► ERROR ◄────────┘
                                               │
                                          OTA_ABORT
                                               │
                                               ▼
                                             IDLE
```

| State | Wire value | Meaning |
|---|---|---|
| `IDLE` | 0 | No transfer in progress. `OTA_BEGIN` is the only op that does anything besides `OTA_STATUS`/`OTA_ABORT` (both harmless no-ops here). |
| `RECEIVING` | 1 | Signature already verified (at `OTA_BEGIN`); accepting `OTA_CHUNK`s in strict offset order. |
| `COMMITTED` | 2 | Image fully received, hash-verified, and flash-finalized into the inactive partition. Awaits an explicit `OTA_REBOOT` — nothing boots automatically. Safe to sit here indefinitely (e.g. rider finishes the ride first); a reconnect can resume by polling `OTA_STATUS` and going straight to `OTA_REBOOT`. |
| `ERROR` | 3 | Last attempt failed. Only `OTA_ABORT` clears it (returns to `IDLE`); no further chunks or commits are accepted until then. |

### 10.2 Trust model

An image must satisfy **both** of the following — either alone is not
sufficient:

1. It arrives over an already-authenticated BLE session (same
   challenge-response as every other channel, §6).
2. Its signature verifies against the project's release public key
   (`MC_OTA_RELEASE_PUBKEY`, `firmware/components/core/mc_ota_release_key.c`)
   — an Ed25519 signature over the image's SHA-512 digest, **not** the raw
   image bytes (this device has no PSRAM to buffer a multi-hundred-KB image
   before hashing it; verifying the signature over the 64-byte digest lets
   `OTA_BEGIN` reject a bad/unsigned image before a single chunk byte is
   accepted).

`OTA_BEGIN`'s `sha512`/`signature` fields and the actual transferred bytes
are cross-checked twice: once at `OTA_BEGIN` (signature over the declared
digest) and once at `OTA_COMMIT` (the running SHA-512 over every
`OTA_CHUNK` byte actually received must equal the declared digest — catches
transport corruption/truncation, which the signature check alone wouldn't).

See §10.4 for how a release image and its signature are produced.

### 10.3 Safe-state gating

`OTA_BEGIN` and `OTA_REBOOT` both additionally require
`!engine_running && !lv_cutoff_active` (the same `engine_running` signal as
starter protection, §12.2, and the low-voltage cutoff, §12.2) — otherwise
they return `REJECTED`. Flashing while riding or while the battery
is critically low is refused. This is re-checked independently at
`OTA_REBOOT` time (not just inherited from `OTA_BEGIN`): a `COMMITTED` image
can sit safely in the inactive partition indefinitely, so nothing is lost if
the bike started moving between commit and reboot — the client just retries
`OTA_REBOOT` later. `OTA_CHUNK`/`OTA_COMMIT` do not re-check this — once
`OTA_BEGIN` has admitted the transfer, the currently-running image is
untouched throughout (writes land in the *inactive* partition), so there is
nothing unsafe about continuing to receive chunks.

### 10.4 Producing a signed release image

`tools/sign-firmware.py` turns a built `moto_ctrl_firmware.bin` into a
`.mcota` bundle — see `docs/PROTOCOL.md`'s companion note in that script's
`--help` and `tools/README.md` for the maintainer key-generation and signing
workflow. A `.mcota` file is a small header (magic, format version, the same
`image_size`/`sha512`/`signature` fields as `OTA_BEGIN`) followed by the raw
image bytes — the app parses that header and feeds its three fields plus
the image bytes straight into `OTA_BEGIN`/`OTA_CHUNK` verbatim. §10.5 below
covers how a `.mcota` bundle reaches the app in the first place.

`firmware/sim` never uses the real release key: it embeds its own fixed
TEST keypair (`firmware/sim/src/main.c`) so `ctest`/the itest suite/app tests
against the simulator can synthesize validly-signed test images without the
real release key ever being involved. `firmware/sim/itest/moto-client.mjs`'s
`otaTransfer()` is a worked reference implementation of the full begin/
chunk-loop/commit sequence against that test key.

### 10.5 App-side update delivery

The app has no way to reach any server except one narrow, permanent
exception to its offline-first design, made for this exact purpose: two
anonymous, read-only HTTPS GETs to one fixed, baked-in URL — a
version-manifest JSON file, then (only if the rider chooses to update) the
`.mcota` bundle it points to. Nothing else is ever sent or requested — no
identifiers, no accounts, and a failed/unreachable check must never block
BLE pairing or control of the board. See `CONTRIBUTING.md`'s "No cloud, no
telemetry, no accounts" section for the full constraints — this section
only documents the file shapes.

Manifest JSON:

```json
{
  "version": "1.2.0",
  "changelog": "Fixes X, adds Y.",
  "bundle_url": "https://.../moto-ctrl-1.2.0.mcota",
  "bundle_sha512": "<128 lowercase hex chars>",
  "bundle_size": 123456
}
```

- `version` is compared against the connected device's `STATUS` firmware
  version (§5) to decide whether to show "update available".
- `bundle_sha512`/`bundle_size` describe the `.mcota` **file** being
  downloaded (transport-integrity check only, done by the app right after
  download, before even attempting a BLE transfer) — distinct from the
  `sha512` field *inside* the `.mcota` header, which is the hash of the raw
  firmware image and is what the device's Ed25519 signature check (§10.2)
  actually relies on for security. A corrupt or tampered manifest can at
  worst point the app at a bad download, which the on-device signature
  check in §10.2 — the real security boundary — still catches.

`.mcota` bundle format (produced by `tools/sign-firmware.py`, parsed by the
app before driving `OTA_BEGIN`/`OTA_CHUNK`):

| Offset | Size | Field |
|---|---|---|
| 0 | 4 | magic: ASCII `"MCOT"` |
| 4 | 1 | format version (currently `1`) |
| 5 | 3 | reserved, must be 0 |
| 8 | 4 | `image_size` (u32le) — matches `OTA_BEGIN`'s field |
| 12 | 64 | `sha512` — SHA-512 of the raw image, matches `OTA_BEGIN`'s field |
| 76 | 64 | `signature` — Ed25519 signature over `sha512`, matches `OTA_BEGIN`'s field |
| 140 | `image_size` | the raw firmware image |

## 11. Lock / immobilizer channel (`2`, COMMAND) — authenticated

The immobilizer state machine's wire ops live on the **same COMMAND
channel** as `SET_OUTPUT` (§7) — they're commands like any other, just
routed to the lock engine instead of the output engine. Simple ops share
the existing `COMMAND_RESULT` `[req_opcode:u8][result:u8]` reply; the two
ops that return a payload get their own response opcode.

| Direction | Opcode | Payload |
|---|---|---|
| → device | `0x02` `LOCK` | — |
| → device | `0x03` `UNLOCK` | — |
| → device | `0x04` `LOCK_GET_CONFIG` | — |
| ← device | `0x84` `LOCK_CONFIG` | see below |
| → device | `0x05` `LOCK_SET_CONFIG` | see below |
| → device | `0x06` `CHEATCODE_SET` | `len:u8` `buttons:u8[len]` |
| → device | `0x07` `CHEATCODE_CLEAR` | — |
| → device | `0x08` `CHEATCODE_TEST` | `len:u8` `buttons:u8[len]` |
| ← device | `0x88` `CHEATCODE_TEST_RESULT` | `result:u8` `match:u8` |
| → device | `0x09` `TRANSFER_OWNERSHIP` | — |

### 11.1 State machine

Four states, reported as the status wire's `lock_state` byte (§5):

| State | Meaning | Wire value |
|---|---|---|
| `DISABLED` | No immobilizer configured (the toggle is off, or no non-phone fallback exists). Nothing inhibited. | `UNLOCKED` (3) |
| `UNLOCKED` | Immobilizer enabled and authorized. Ignition permitted. | `UNLOCKED` (3) |
| `PARKED` | Enabled and unlocked, engine off *and* ignition output off. Auto-lock grace timer running. | `PARKED` (1) |
| `LOCKED` | Enabled and immobilized. **Every** output refused from any source, except the hazard control. | `LOCKED` (2) |

`DISABLED` and `UNLOCKED` share a wire value, so a client that needs to know
whether an immobilizer exists at all must read the lock config (§11.2), not
the status byte.

**What LOCKED actually inhibits.** Every channel, not just ignition and
starter: `mc_output_set(..., on = true)` returns `IMMOBILIZED` for any channel
while the flag is set. A locked bike whose headlight and horn still answered
to anyone walking past was not immobilized in any sense a rider would
recognise. Switching outputs **off** is never blocked.

`HAZARD_PRESS` is the one exception and still works while locked — a bike
broken down at the roadside has to stay visible, and its rider may well have
locked it before walking off. The exemption is the hazard *control*:
commanding an individual hazard-group member is still refused.

**Entering LOCKED turns the board off.** Every commanded channel is switched
off as the lock engages, so a forgotten headlight can't flatten the battery
overnight. Hazards that are *already running* are left alone, for the same
roadside reason.

**Leaving LOCKED turns the key.** Unlocking — by any method — energises the
ignition output, so the bike is ready to start rather than needing a second
action the rider has no reason to expect. This runs through the ordinary
output path, so `on_with_ignition` channels (§9) light with it and the
starter's own guards are untouched: unlocking never cranks anything.

```
                 immobilizer enabled (cheat-code set)
   ┌──────────┐  ───────────────────────────────────►  ┌──────────┐
   │ DISABLED │                                          │ UNLOCKED │◄────────┐
   └──────────┘  ◄───────────────────────────────────   └────┬─────┘         │
        ▲          disable / factory reset / transfer         │ engine off &  │ engine on OR
        │                                                      │ ign not live │ ignition live
        │  factory reset / ownership transfer                 ▼               │
        │  (from any state)                              ┌──────────┐         │
        └────────────────────────────────────────────    │  PARKED  │─────────┘
                                                           └────┬─────┘
                          grace timer elapsed  OR              │  guard: !engine_running
                          explicit LOCK (authed)                ▼  && !ignition_live
                                                           ┌──────────┐
                                 any enabled unlock        │  LOCKED  │
                                 method succeeds  ◄─────── │ (+ cheat-│
                                 → UNLOCKED                │  code    │
                                                            │ backoff) │
                                                            └──────────┘
```

Boot restore is ride-safe (see `CONTRIBUTING.md`'s safety requirement #1):
the device never restores into `LOCKED` while the engine appears to be
running or the ignition output is already live — a brownout mid-ride
always restores the bike running, never immobilized. `LOCK` (explicit)
refuses with `REJECTED` unless `!engine_running && !ignition_live` holds
at the moment of the request, mirroring safety requirement #2 ("lock state
may only be entered from parked, never while ignition output is live")
exactly.

### 11.2 Method truth table

Three unlock methods, controlled by `LOCK_SET_CONFIG`'s `methods_mask` bits
(`PHONE = 0x01`, `IGNITION_SWITCH = 0x02`) plus the always-on cheat-code:

- **The button cheat-code is not a `methods_mask` bit** — it is always
  active whenever the immobilizer is enabled, and cannot be disabled while
  it is (`CONTRIBUTING.md` safety requirement #3's mandatory fallback).
  `LOCK_SET_CONFIG` with `immobilizer_enabled=1` is refused (`REJECTED`)
  unless a cheat-code is already set via `CHEATCODE_SET`.
- **Every enabled method works simultaneously** — there is no "pick one."
- **Phone-as-key unlock is edge-triggered**, not proximity-polled: it fires
  when a session's challenge-response *newly* succeeds (§6), not
  continuously while a session stays connected. This is deliberate — a
  level-triggered design would make an explicit `LOCK` self-defeating
  while the same phone that just issued it stays connected (it would
  immediately re-unlock). A phone that was already authenticated before
  the bike locked stays able to unlock via the explicit `UNLOCK` op.
- **Ignition-switch mode does not replace the cheat-code.** The handlebar
  buttons have no wiring of their own to fail; a dedicated ignition-switch
  wire is a single point of failure that must never be the *only*
  fallback. Both may be enabled together.
- **An in-range/authenticated phone never suppresses the cheat-code** —
  physical entry works regardless of phone presence (for a dead phone, or
  lending the bike to someone without pairing their phone).
- A fresh or factory-reset device boots with the immobilizer **disabled**
  until the owner configures a method — a device can never lock with no
  configured way back in.

### 11.3 `LOCK` / `UNLOCK`

`LOCK`: locks now if the immobilizer is enabled and the guard
(`!engine_running && !ignition_live`) holds. `REJECTED` if the guard fails
or the immobilizer isn't enabled. Idempotent — locking an already-`LOCKED`
bike returns `OK`. Works from `UNLOCKED` or `PARKED` (doesn't require
waiting for the auto-lock grace timer).

`UNLOCK`: phone-as-key unlock from an authenticated session (the PHONE
`methods_mask` bit must be set, else `REJECTED`). A no-op `OK` if the bike
isn't currently `LOCKED`. This is the explicit counterpart to the
edge-triggered auto-unlock described in §11.2 — use it when the session
authenticated *before* the bike became `LOCKED`.

### 11.4 Cheat-code: storage, entry, and lockout

The cheat-code is **never transmitted or stored in cleartext** — the
device stores a salted SHA-512 hash (`salt(16) || len(1) || buttons`) in
its own NVS blob, deliberately **not** part of the exportable JSON config
(§9) — same doctrine as the keystore (§6): a flash/NVS dump or a restored
config backup cannot reveal or replay it.

- `CHEATCODE_SET` `[len:u8][buttons:u8[len]]`: `len` must be 4–10, each
  button index 0–7 (matching the combo matcher's own bounds). Replaces any
  existing code; resets the in-progress entry buffer and lockout counter.
  `BAD_REQUEST` if `len`/buttons are out of range.
- `CHEATCODE_CLEAR`: `REJECTED` while `immobilizer_enabled` is true (the
  mandatory fallback can't be removed out from under an active
  immobilizer — disable the immobilizer first).
- `CHEATCODE_TEST` `[len:u8][buttons:u8[len]]` → `CHEATCODE_TEST_RESULT`
  `[result:u8][match:u8]`: a **practice mode** — pure hash comparison, no
  side effects (never touches the entry buffer, the lockout counter, or
  lock state). Authenticated-only, same trust boundary as every other
  command on this channel.
- **Physical entry** is not an RPC — there is no "submit code" opcode. The
  device buffers short button presses (from the handlebar input engine)
  while the bike is `LOCKED`, evaluating as soon as the buffer reaches the
  configured length, within a configurable entry window
  (`cheatcode_window_ms`, default 5000ms; an incomplete/timed-out entry is
  not counted as wrong). Presses are ignored entirely while not `LOCKED`,
  so ordinary riding (turn-signal/horn presses on the same 8 buttons)
  never accumulates wrong-entry counts.

**Wrong-entry backoff** (byte 15 bit 0 of the status wire reports whether
it's currently active): the first **5** wrong entries are free (no
cooldown — cold hands, a fumbled sequence, roadside stress). The 6th wrong
entry starts a progressive cooldown: 15s, then 30s, then a 60s cap. During
backoff, cheat-code presses are ignored entirely — **phone-as-key and the
ignition switch are never gated by this backoff**, so the rider is never
actually locked out (`CONTRIBUTING.md` safety requirement #3). The counter
resets on any successful
unlock (any method) or after 5 minutes with no attempts. This state is
RAM-only — it resets on reboot, since the cheat-code is a low-entropy
convenience fallback, not the primary security boundary.

### 11.5 `LOCK_GET_CONFIG` / `LOCK_SET_CONFIG`

`LOCK_GET_CONFIG` (no payload) → `LOCK_CONFIG`:

| Offset | Size | Field |
|---|---|---|
| 0 | 1 | `immobilizer_enabled` |
| 1 | 1 | `methods_mask` (bit 0 = PHONE, bit 1 = IGNITION_SWITCH) |
| 2 | 1 | `ignition_switch_input` (0–7, or `0xFF` = none) |
| 3 | 2 | `auto_lock_grace_ms` (u16le) |
| 5 | 2 | `cheatcode_window_ms` (u16le) |
| 7 | 1 | `cheatcode_set` |
| 8 | 1 | `cheatcode_len` |

Never includes the cheat-code salt/hash — the device is the only party
that ever needs them.

`LOCK_SET_CONFIG` `[immobilizer_enabled:u8][methods_mask:u8][ignition_switch_input:u8][auto_lock_grace_ms:u16le][cheatcode_window_ms:u16le]`
→ `COMMAND_RESULT`. Validated before applying (`REJECTED` on failure, config
unchanged): enabling requires **at least one non-phone unlock method** — a
cheat-code already set (§11.2) *or* `IGNITION_SWITCH` enabled with a valid
`ignition_switch_input` — *and* an `is_ignition` output channel configured
(§9 — nothing to immobilize otherwise); enabling `IGNITION_SWITCH` requires a
valid `ignition_switch_input` (0–7).

The fallback rule: the phone may never be the only way in, so
a flat phone battery can't strand the rider. It used to require the
cheat-code specifically; a rider with an OEM key switch wired to an input
already has a physical fallback, and forcing them to also set a code they
would never use bought no safety. A method bit pointing at no assigned input
does **not** count — that is a `BAD_IGNITION_SWITCH_INPUT` *and* a missing
fallback. Leaves the cheat-code itself untouched — it's only ever changed via
`CHEATCODE_SET`/`CHEATCODE_CLEAR`. `ignition_switch_input` reuses an input
index exactly like `starter_interlock_input` (§9) — it is not a separate
physical signal, just a debounced-level read of one of the 8 handlebar
inputs (a maintained switch wired to one of CN2's button inputs, not a
momentary button).

### 11.6 Ownership transfer & factory reset

`TRANSFER_OWNERSHIP` (authenticated, no payload): wipes every enrolled key
(§6), resets `device_name` to the factory default (§9 — the nickname goes
with the old owner), and resets the lock config to factory defaults
(immobilizer disabled,
no cheat-code, no ignition-switch assignment) in one atomic operation,
releasing any active immobilize. Requires an authenticated session, so a
thief can't wipe the owner's keys. After it: the keystore is empty, so
trust-on-first-use enrollment (§6) reopens for the next owner, and the
immobilizer stays disabled until they configure a non-phone unlock method.

The **physical** factory reset (`CONTRIBUTING.md` safety requirement #3:
hold BOOT for 10s at power-on, confirmed by a distinct pattern before
wiping) reaches the same
end state without any session or key — it's for the no-phone/lost-owner
case. It is bench/board-only; there is no BLE/WebSocket op for it, since
by definition it works with no live session. See
`firmware/main/factory_reset.c`.

## 12. Diagnostics channel (`2`, COMMAND) — authenticated

Current-sense diagnostics, `engine_running` (see §12.2 and
`CONTRIBUTING.md` safety requirement #6 — an unconditional ignition-off
override plus opt-in voltage-based detection, not battery-derived alone)
and low-voltage cutoff (safety requirement #7) live on the same COMMAND
channel as `SET_OUTPUT` (§7) and the lock ops (§11). Same conventions as
§11: `COMMAND_RESULT` for simple ops, a dedicated response opcode where
there's a payload — but every dedicated response here **leads with a
`result:u8` byte** (unlike `LOCK_CONFIG`), so a device with diagnostics
unavailable can still reply with a well-formed, zeroed frame carrying
`REJECTED` rather than needing a second error path.

| Direction | Opcode | Payload |
|---|---|---|
| → device | `0x0A` `DIAG_GET` | — |
| ← device | `0x8A` `DIAG_RESULT` | see §12.3 |
| → device | `0x0B` `DIAG_GET_CONFIG` | — |
| ← device | `0x8B` `DIAG_CONFIG` | see §12.4 |
| → device | `0x0C` `DIAG_SET_CONFIG` | see §12.4 |
| → device | `0x0D` `DIAG_GET_CALIB` | — |
| ← device | `0x8D` `DIAG_CALIB` | see §12.6 |
| → device | `0x0E` `DIAG_SET_CALIB` | see §12.6 |
| → device | `0x0F` `DIAG_LEARN` | `channel:u8` (`0xFF` = every energized channel) |

### 12.1 Current-sense sampling and fault classification

Hardware (`hardware/PINOUT.md`): 6 PROFETs (2 output channels each) share
one current-sense ADC line, muxed by a shared `DSEL` select plus one
device's `DEN` at a time — only one channel's current can be read at once,
so the device **round-robin samples one actually-energized channel per
~10ms tick** rather than all 12 simultaneously. A channel that is not
actually energized — commanded off, *or* suppressed by the low-voltage
cutoff (§12.4) — always reports `0mA` and is never fault-classified; a
channel genuinely drawing no current only faults if it is supposed to be
driving a load right now.

Per channel, the device classifies the calibrated reading against two
configurable thresholds (§12.6, §9): below `open_load_ma` while energized ⇒
`OPEN_LOAD` (1); above `overcurrent_ma` ⇒ `OVERCURRENT` (2); otherwise
`NONE` (0). These three values are `mc_diag_fault_t`; a value of `3`
(`SHORT`) exists only in the pre-hardware simulator's fault-injection wire
shape (`firmware/sim/src/sim_protocol.h`) and is never produced by real
classification.

### 12.2 Battery, `engine_running`, and the low-voltage cutoff

The battery-sense ADC line is read every tick and calibrated the same way
(§12.6). Two signals are derived from it, each with its own configurable
threshold **and hysteresis band** (§9) to avoid chatter at the boundary:

- **`engine_running`** (see `CONTRIBUTING.md` safety requirement #6): two
  independent contributors, either of which can set it.
  - **Voltage-based detection**, gated behind `engine_run_voltage_detection_enabled`
    (**OFF by default**): while enabled, set once the battery reading is at
    or above `engine_run_mv` (default 13.8V — deliberately well above a
    fully-charged LiFePO4 pack's resting voltage, so a healthy-but-idle
    battery is never mistaken for a running/charging engine), cleared once
    it drops below `engine_run_mv - engine_run_hysteresis_mv`. Off by
    default because voltage alone cannot distinguish a running alternator
    from a booster pack or a bench PSU holding the line above threshold —
    with detection on, jump-starting a dead bike would find the starter
    refused (`MC_OUT_ERR_STARTER_ENGINE_RUNNING`) exactly when it's needed.
  - **Ignition-off override**, unconditional and independent of the toggle
    above: whenever an output channel is assigned `is_ignition` and it is
    not currently on, `engine_running` is forced false, full stop — an
    engine cannot run with its ignition off, regardless of what a booster
    pack or bench PSU is doing to the battery line. No channel assigned
    means no override; voltage detection (if enabled) then stands on its
    own.

  Either contributor drives the starter-protection guard (§7's `SET_OUTPUT`
  rejection reasons) and the lock state machine's parked-detection guard
  (§11.1).
- **Low-voltage cutoff** (safety requirement #7): engages once the battery
  reading drops below `lv_cutoff_mv` (default 11.8V for LiFePO4) **and only
  while `!engine_running`** — a charging system holding voltage up must never be
  second-guessed by a stale low reading. Recovers once the reading is back
  at or above `lv_cutoff_mv + lv_cutoff_hysteresis_mv`. A raw reading of
  exactly `0mV` (an unread/failed ADC line, far more likely than a
  genuinely dead battery) is treated as "unknown" and never engages the
  cutoff on its own.

**Cutoff behavior is a suppression, not a command change.** While active,
every **non-essential** output channel — everything except `ignition`,
`brake`, `headlight_hi`, and `headlight_lo` (`CONTRIBUTING.md` safety
requirement #1's "never drop these mid-ride" set; the starter is excluded
too, since it already has its own dedicated guards) — is driven off at the
hardware regardless of its
commanded state, but `commanded_on` itself, and therefore
**`output_state_mask` (§5), is left untouched**. This mirrors a real
vehicle: a blown fuse or protection circuit doesn't move the switch. The
app must read status wire byte 15 bit 1 (`lvCutoffActive`), not a change in
`output_state_mask`, to know a channel is currently suppressed; recovery
needs no separate command — every channel returns to its last-commanded
state automatically.

### 12.3 `DIAG_GET` / `DIAG_RESULT`

`DIAG_GET` (no payload) → `DIAG_RESULT`:

```
[result:u8]
[current_ma:u16le] × 12   (channels 0-11, in order)
[fault:u8] × 12           (mc_diag_fault_t, channels 0-11, in order)
```

37 bytes total (plus the leading opcode byte on the wire) — the live
per-channel readings from §12.1, as of each channel's last round-robin
sample.

### 12.4 `DIAG_GET_CONFIG` / `DIAG_SET_CONFIG`

`DIAG_GET_CONFIG` (no payload) → `DIAG_CONFIG`:

```
[result:u8]
([open_load_ma:u16le][overcurrent_ma:u16le]) × 12   (channels 0-11)
[lv_cutoff_mv:u16le][lv_cutoff_hysteresis_mv:u16le]
[engine_run_mv:u16le][engine_run_hysteresis_mv:u16le]
[engine_run_voltage_detection_enabled:u8]
```

58 bytes total (the trailing byte added at the same time as
`schema_version` 9's JSON field, §9). `DIAG_SET_CONFIG` sends the same
shape **without** the leading `result` byte (57 bytes) → `COMMAND_RESULT`.
`REJECTED` if any channel's `open_load_ma >= overcurrent_ma` (never
classifiable as `OVERCURRENT` — not unsafe, just certainly a
misconfiguration); config unchanged on rejection. On success, both the live
engine and the persisted `mc_config_t.diagnostics` (§9) are updated — a
config export/import round-trips these thresholds too.

Unlike the JSON config, this is a fixed-shape binary payload with no
tolerance for a missing trailing field: a client sending the pre-9
57/56-byte shape will have its `DIAG_SET_CONFIG` rejected (`BAD_REQUEST`)
rather than the new field silently defaulting, and firmware built before
this field existed will not populate it in `DIAG_CONFIG` at all. There is
no opcode/version negotiation on this channel — a client must be updated
to match whichever firmware it's talking to.

### 12.5 `DIAG_LEARN`

`DIAG_LEARN` `[channel:u8]` (`0xFF` = every currently-energized channel) →
`COMMAND_RESULT`. Samples the live current of each targeted channel and
sets its `open_load_ma` to roughly half the measured healthy draw — a
subsequent real fault (bulb blows, connector opens) still trips well above
zero but comfortably below a healthy reading (thresholds are always
learnable, never hardcoded to an assumed bulb). Never touches
`overcurrent_ma`. `REJECTED` if the targeted channel (or, for `0xFF`, every
channel) isn't actually energized — there's nothing to measure.

### 12.6 `DIAG_GET_CALIB` / `DIAG_SET_CALIB`

Board-specific analog calibration — deliberately **not** part of the config
JSON (§9) or a config export/import: applying board A's gain/offset/kILIS
constants to board B would silently misreport board B's real current and
voltage. Persisted in its own NVS blob and, unlike a factory reset /
`TRANSFER_OWNERSHIP` (§11.6), **not wiped by either** — it describes the
physical board, not the outgoing owner.

`DIAG_GET_CALIB` (no payload) → `DIAG_CALIB`:

```
[result:u8]
[is_gain:f32le][is_offset_mv:i16le]
[kilis:f32le]
[vbat_gain:f32le][vbat_offset_mv:i16le]
```

17 bytes total. `DIAG_SET_CALIB` sends the same shape without the leading
`result` byte (16 bytes) → `COMMAND_RESULT`. `f32le` is IEEE754 binary32,
little-endian — standard on every platform this project targets (ESP32-S3,
x86/ARM hosts, and JS via `DataView.getFloat32(offset, true)`).
`is_gain`/`is_offset_mv` correct the current-sense (`PROFET_IS`) reading;
`kilis` is the BTS7008-2EPA datasheet's current-sense ratio
(`I[mA] = (V_IS[mV] / 2000) * kilis`, 2kΩ sense resistor, `hardware/
PINOUT.md`); `vbat_gain`/`vbat_offset_mv` correct the battery-divider
reading. No validation beyond payload shape — these are installer/bench
values, trusted like the rest of this authenticated channel.

## 13. Flashers / PWM channel (`2`, COMMAND) — authenticated

Turn signals, hazard, brake flasher, and PWM dimming. Mode, duty, timing,
and the brake-switch input assignment all ride the config JSON (§9) — there
are no dedicated get/config wire ops here, unlike lock (§11) or diagnostics
(§12), since output config never had its own dedicated channel to begin
with (function/name/mode have always been generic config JSON fields). The
**one** dedicated opcode here is `HAZARD_PRESS`.

### 13.1 Turn signals — `SET_OUTPUT` (§7), no new opcode

A plain turn-signal press is just `SET_OUTPUT` on the `turn_l`/`turn_r`-
function channel — the policy below is embedded in the device's output
engine itself (`mc_output_set()`), so it applies automatically to any
caller (a handlebar button locally, or this wire op), the same way starter
protection and the low-voltage cutoff already do:

- Turning a `turn_l`/`turn_r` channel **on** forces the opposite side off
  (mutual exclusion — only one side signals at a time) and arms the
  configured auto-cancel timer (`outputs.turn_auto_cancel_ms`, §9; `0`
  disables it — manual toggle only).
- Turning it **off** clears that channel's pending auto-cancel timer.
- The auto-cancel timer expiring is **not** a wire event — a client that
  cares should just poll `STATUS` (§5); `output_state_mask` clears the bit
  the same way any other commanded-off transition does.

A `flash_turn`-mode channel (§9's `mode`) blinks at
`outputs.turn_flash_period_ms` while commanded on; the blink itself is not
observable on the wire (see §13.3).

### 13.2 Hazard — `HAZARD_PRESS`

| Direction | Opcode | Payload |
|---|---|---|
| → device | `0x10` `HAZARD_PRESS` | — |
| ← device | `0x81` `COMMAND_RESULT` | `req_opcode:u8` `result:u8` |

Toggles both `turn_l` and `turn_r` channels together: if either is
currently off, turns both on; if both are already on, turns both off. This
needs its own opcode because "both sides on together" can't be expressed
as two `SET_OUTPUT` calls without the mutual-exclusion rule above
cancelling the first one. No auto-cancel timer is armed either way —
hazards stay on until pressed again (like a real hazard switch), and
remain subject to the low-voltage cutoff (§12) like any non-essential
channel. `REJECTED` if neither a `turn_l` nor a `turn_r` channel is
configured.

### 13.3 Brake flasher

A `brake`-function channel defaults to plain `on` mode (steady, follows
commanded state) — the attention-pulse burst is opt-in via
`mode: "flash_brake"`, off by default, because flash patterns are not
legal in every jurisdiction (see `CONTRIBUTING.md` safety requirement #5).
In `flash_brake` mode, the channel's off→on transition plays a burst of
`outputs.brake_flash_pulse_count` pulses (`_on_ms` lit, `_off_ms` dark
each) before settling solid; the off-phases are deliberately short
relative to the on-phases so the light spends the overwhelming majority of
the burst lit, in keeping with that same requirement that the brake light
is on whenever the brake input is asserted. Turning the channel off is
always immediate — never mid-pattern.

There's no dedicated "brake pressed" opcode: a physical brake-lever/pedal
switch is assigned to one of the 8 button inputs via
`outputs.brake_switch_input` (§9) and read as a maintained level (mirrors
`starter_interlock_input`'s pattern), which the firmware turns into an
ordinary `SET_OUTPUT`-equivalent transition on the `brake`-function
channel — the same path an app-issued `SET_OUTPUT` on that channel would
take (useful for bench testing without a wired switch).

### 13.4 PWM dimming

`mode: "pwm"` (§9) drives a channel at a steady `pwm_duty_pct` (1–100)
while commanded on, instead of full on/off. Opt-in per channel, off by
default — driver-based LED lamps can misbehave under PWM. Flasher
patterns (§13.1, §13.3) never use PWM —
they're always full on/off switching, so every lamp type works without
hyperflash workarounds.

### 13.5 What's not on the wire

No status-snapshot changes this phase: a client can already tell whether a
turn/hazard signal is commanded active from `output_state_mask` (§5) on
the `turn_l`/`turn_r` channels, the same way it already reads any other
channel's intent. Instantaneous blink phase / burst-pulse phase is **not**
exposed over the wire — same design choice as the low-voltage cutoff
(§12): the app shows commanded intent, not sub-second HAL state, and a
phone polling at a human-relevant rate has no real use for it anyway.

## 14. Security summary

- Link is encrypted and bonded via LE Secure Connections.
- Authority comes from the Ed25519 challenge-response, not the link or MAC.
- The device stores **only public keys**, and only a **salted hash** of the
  cheat-code; a flash/NVS dump cannot unlock the bike, forge a key, or
  recover the cheat-code.
- Nonces are single-use and per-session; signatures cannot be replayed.
- The starter is never actuable over this protocol; neither is the
  ignition output while the immobilizer is `LOCKED` (§11).
- Authentication is one-way (client proves possession of an enrolled key to
  the device). A future revision may add device-to-client authentication.

## 14.1 Button identification (COMMAND channel `2`) — authenticated

A rider who has just wired eight handlebar buttons has no idea which one is
input 3. Learn mode answers that: while it is on, every debounced press is
pushed to the requesting session, so the app can say "that was input 5" and
offer to name it (`inputs.names`, §9).

| Direction | Opcode | Payload |
|---|---|---|
| → device | `0x12` `INPUT_LEARN` | `enable:1` (0 = off, non-zero = on) `[suppress_actions:1]` (optional) |
| ← device | `0x92` `INPUT_EVENT` | `button:1` `press_type:1` `action_suppressed:1` |

- `press_type`: `0` short, `1` long, `2` double.
- `action_suppressed`: `1` when a chord consumed this press, so its own
  binding deliberately did not fire (§9). Lets the UI explain the behaviour
  rather than looking broken.
- `suppress_actions` (optional second byte, default 0): while set, the device
  reports presses **without running their handlebar bindings**. Intended for
  capturing a cheat-code, where the rider presses whichever buttons make up
  their code and would otherwise sound the horn or flash the indicators once
  per press. It applies to press-event dispatch *and* to level-driven
  momentary channels, which would otherwise still follow the hold; a momentary
  output already held when suppression begins goes off rather than latching.

  Handlebar controls are inert for the duration, so a client should only ask
  for it in a mode the rider deliberately entered and can see. Two things are
  never suppressed: the **cheat-code matcher** itself, which is layered unlock's
  unlock fallback and must not be disableable from the app, and the
  **brake-switch pass-through**, which is the brake-light
  guarantee.

  Omitting the byte means "don't suppress", so a client written against the
  earlier one-byte payload keeps its previous behaviour.
- Replies to `INPUT_LEARN` with the usual `COMMAND_RESULT`; a missing
  `enable` byte is `BAD_REQUEST`.

Learn mode is **off by default and opt-in per session**, never a broadcast:
the board must not stream an event for every handlebar press for the length
of a ride (radio and battery discipline). The flag lives in the
session, so a disconnect always ends it and no timeout is needed. Enabling it
does not change dispatch — bindings still fire normally; this is telemetry
running alongside them, not instead of them.

`INPUT_EVENT` is one of the few genuinely unsolicited device-to-client
frames: it arrives with no preceding request, at whatever rate the rider
presses buttons. A client must tolerate it appearing between the request and
reply of any other COMMAND-channel op.
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

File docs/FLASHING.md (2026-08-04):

# Flashing MOTO-CTRL firmware

This board programs over **UART0 only** — there is no USB port, and no
auto-reset circuit (the RC/DTR-RTS reset network a typical ESP32 dev board
has). You need a separate 3.3V USB-to-serial adapter and you enter the
bootloader manually with two buttons. This guide covers both the initial
flash of a bare board and reflashing an already-running one over UART; for
day-to-day firmware updates once the board is paired to the app, use OTA
instead (see "OTA vs. UART" below).

Read [`DISCLAIMER.md`](../DISCLAIMER.md) before flashing a board that's
wired into a motorcycle. Bench-test any new firmware build before riding
with it.

## What you need

- A 3.3V-logic USB-to-serial adapter (e.g. an FTDI FT232RL board, a
  CP2102/CH340 adapter, or similar) set to **3.3V**, not 5V. The board's
  UART pins are not 5V-tolerant.
- Three jumper wires.
- A way to power the board: either bench 12V (10–15V, see
  [`hardware/PINOUT.md`](../hardware/PINOUT.md)) or the motorcycle's own
  12V feed. **Do not power the board from the USB adapter's 5V/3V3 pin** —
  the board runs from its own 12V input, not from UART.
- The [ESP-IDF](https://docs.espressif.com/projects/esp-idf/en/stable/esp32s3/get-started/index.html)
  toolchain (for `idf.py flash`), or just `esptool.py` if you already have a
  built `.bin` and don't want the full toolchain.

## Wiring the UART adapter

The board exposes a 3-pin header (H1) for programming — see
[`hardware/PINOUT.md`](../hardware/PINOUT.md)'s "System / programming"
table:

| H1 pin | Signal | ESP32 GPIO | Connect to adapter |
|---|---|---|---|
| 1 | TX (board → adapter) | GPIO43 / TXD0 | adapter **RX** |
| 2 | RX (adapter → board) | GPIO44 / RXD0 | adapter **TX** |
| 3 | GND | — | adapter **GND** |

TX/RX are crossed, as with any serial link: the board's TX goes to the
adapter's RX, and vice versa. Do not connect the adapter's power pin to the
board at all.

## Entering the bootloader (manual BOOT/EN sequence)

Because there's no auto-reset circuit, you put the chip into its UART
download mode by hand, using the two buttons next to H1
([`hardware/PINOUT.md`](../hardware/PINOUT.md)'s BOOT/SW2 and RESET/SW1):

1. Power the board (bench supply or vehicle 12V) and connect the UART
   adapter to your computer, but don't start a flash yet.
2. **Press and hold BOOT (SW2).**
3. While still holding BOOT, **press and release RESET (SW1)** once.
4. **Release BOOT.**
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

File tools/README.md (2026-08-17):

# tools/

Scripts supporting development and releases.

Most of these are wrapped by the root [`Makefile`](../Makefile) — `make
release v=X.Y.Z` bumps the version, builds, and signs; `make publish
v=X.Y.Z` additionally tags and creates the GitHub Release. Run `make help`
for the full list. Use the scripts directly when you need a step on its own.

- [`bump_version.py`](bump_version.py) — sets the firmware version across
  every file that has to agree on it (the `MC_FW_VERSION_*` macros that ship
  in the STATUS wire reply, and the integration test's hardcoded assertion).
  The app is versioned separately, in `app/package.json`, and is not touched.
- [`bootstrap-app-native.sh`](bootstrap-app-native.sh) — regenerates
  `app/ios/` and `app/android/` from the pinned React Native template. Both
  are already committed, so this is only for a React Native upgrade or a
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

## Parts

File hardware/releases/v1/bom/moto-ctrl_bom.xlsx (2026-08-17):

No. | Quantity | Comment | Designator | Footprint | Value | Manufacturer Part | Manufacturer | Supplier Part | Supplier
1 | 2 | 10uF | C1,C33 | C0603 | 10uF | CL10A106KP8NNNC | SAMSUNG(三星) | C19702 | LCSC
2 | 2 | 100nF | C2,C5 | C0402 | 100nF | CL05B104KO5NNNC | SAMSUNG(三星) | C1525 | LCSC
3 | 1 | 1uF | C3 | C0402 | 1uF | CL05A105KA5NQNC | SAMSUNG(三星) | C52923 | LCSC
4 | 1 | 1nF | C4 | C0402 | 1nF | 0402B102K500NT | FH(风华) | C1523 | LCSC
5 | 6 | 100nF | C6,C7,C12,C13,C18,C19 | C0603 | 100nF | CC0603KRX7R9BB104 | YAGEO(国巨) | C14663 | LCSC
6 | 20 | 10nF | C8,C9,C10,C11,C14,C15,C16,C17,C20,C21,C22,C23,C24,C25,C26,C27,C28,C29,C30,C31 | C0603 | 10nF | 0603B103K500NT | FH(风华) | C57112 | LCSC
7 | 2 | 1uF | C32,C34 | C0805 | 1uF | CL21B105KBFNNNE | SAMSUNG(三星) | C28323 | LCSC
8 | 1 | KF142V-5.08-12P | CN1 | CONN-TH_12P-P5.08_KF142V-5.08-12P |  | KF142V-5.08-12P | KEFA(科发) | C475143 | LCSC
9 | 1 | KF142V-5.08-8P | CN2 | CONN-TH_8P-P5.08_KF142V-5.08-8P |  | KF142V-5.08-8P | KEFA(科发) | C475140 | LCSC
10 | 1 | SMBJ20A | D1 | SMB_L4.6-W3.6-LS5.3-RD |  | SMBJ20A | MDD(辰达半导体) | C364296 | LCSC
11 | 1 | SS34 | D2 | SMA_L4.3-W2.6-LS5.2-RD |  | SS34 | MDD(辰达半导体) | C8678 | LCSC
12 | 1 | PZ254V-11-03P | H1 | HDR-TH_3P-P2.54-V-M_PZ254V-11-03P |  | PZ254V-11-03P | XFCN(兴飞) | C2937625 | LCSC
13 | 13 | KT-0603R | LED1,LED2,LED3,LED4,LED5,LED6,LED7,LED8,LED9,LED10,LED11,LED12,LED13 | LED-SMD_L1.6-W0.8-R-RD |  | KT-0603R | KENTO | C2286 | LCSC
14 | 9 | 10kΩ | R1,R49,R50,R51,R52,R53,R54,R55,R56 | R0402 | 10kΩ | RC0402FR-0710KL | YAGEO(国巨) | C60490 | LCSC
15 | 21 | 2.2kΩ | R2,R28,R29,R30,R31,R32,R33,R34,R35,R36,R37,R38,R39,R41,R42,R43,R44,R45,R46,R47,R48 | R0603 | 2.2kΩ | 0603WAF2201T5E | UNI-ROYAL(厚声) | C4190 | LCSC
16 | 1 | 2kΩ | R3 | R0603 | 2kΩ | 0603WAF2001T5E | UNI-ROYAL(厚声) | C22975 | LCSC
17 | 25 | 4.7kΩ | R4,R5,R6,R7,R8,R9,R10,R11,R12,R13,R14,R15,R16,R17,R18,R19,R20,R21,R22,R23,R24,R25,R26,R27,R40 | R0603 | 4.7kΩ | 0603WAF4701T5E | UNI-ROYAL(厚声) | C23162 | LCSC
18 | 1 | 100kΩ | R57 | R0603 | 100kΩ | 0603WAF1003T5E | UNI-ROYAL(厚声) | C25803 | LCSC
19 | 1 | 1MΩ | R58 | R0603 | 1MΩ | 0603WAF1004T5E | UNI-ROYAL(厚声) | C22935 | LCSC
20 | 2 | TS-1187A-B-A-B | SW1,SW2 | SW-SMD_4P-L5.1-W5.1-P3.70-LS6.5-TL_H1.5 |  | TS-1187A-B-A-B | XKB Connection(中国星坤) | C318884 | LCSC
21 | 1 | 2.4GHz | U1 | WIFIM-SMD_ESP32-S3-WROOM-1-N8 | 2.4GHz | ESP32-S3-WROOM-1-N4 | ESPRESSIF(乐鑫) | C2913197 | LCSC
22 | 6 | BTS7008-2EPA | U2,U3,U4,U5,U6,U7 | PG-TSDSO-14_L4.9-W3.9-P0.65-LS6.0-BL-EP |  | BTS7008-2EPA | Infineon(英飞凌) | C534830 | LCSC
23 | 1 | 100uF | U9 | CAP-SMD_BD8.0-L8.3-W8.3-LS9.1-FD | 100uF | RVT1H101M0810 100UF 50V | DMBJ(振宝佳) | C970687 | LCSC
24 | 1 | R-78E3.3-1.0 | U10 | PWRM-TH_R-78EXX-1.0 |  | R-78E3.3-1.0 | YLPTEC(易川) | C22371889 | LCSC

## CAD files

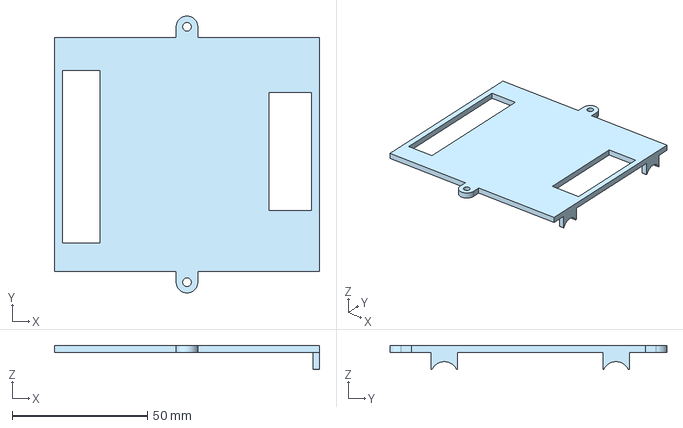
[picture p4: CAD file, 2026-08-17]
enclosure/v1/moto-ctrl-lid-v1.step
98.0 x 102.3 x 9.03 mm

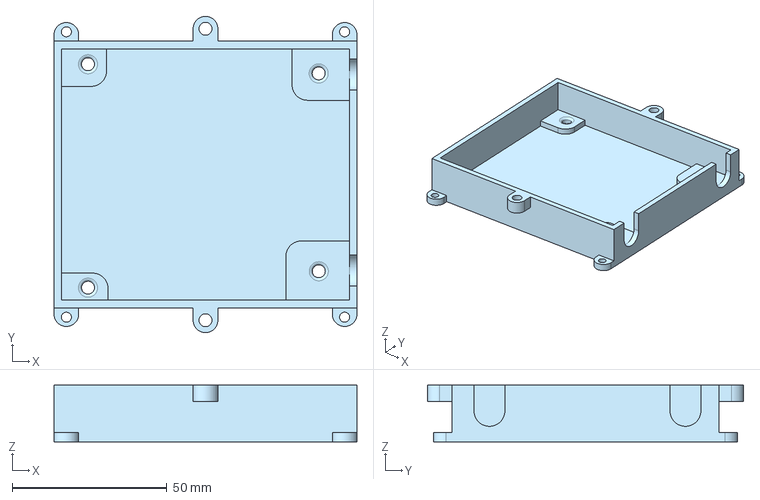
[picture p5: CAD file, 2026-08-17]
enclosure/v1/moto-ctrl-enclosure-v1.step
98.0 x 102.3 x 18.3 mm

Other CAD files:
enclosure/v1/moto-ctrl-enclosure-v1.stl
enclosure/v1/moto-ctrl-lid-v1.stl

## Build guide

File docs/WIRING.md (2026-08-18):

# Wiring MOTO-CTRL to a motorcycle

**Read [`DISCLAIMER.md`](../DISCLAIMER.md) in full before wiring anything
to your bike.** MOTO-CTRL switches lighting, signaling, ignition, and
starter circuits. It is not a certified automotive device. You are
responsible for verifying this wiring is correct and safe for your
specific motorcycle, fusing every circuit appropriately, and bench-testing
before you ride.

This guide covers the general procedure and terminal layout that apply to
any installation. It cannot cover your specific motorcycle's wire colors,
connectors, or circuit locations — those vary by make, model, and year.
Use your bike's factory wiring diagram (or a multimeter and patience) to
identify the actual circuits before connecting anything.

## Before you start

- **Every output channel is generic hardware — function is assigned in the
  app, not by which terminal you use.** OUT1 through OUT12 (CN1) are twelve
  electrically identical high-side switched outputs (see
  [`hardware/PINOUT.md`](../hardware/PINOUT.md)); there is no "the brake
  light terminal" printed on the board. You wire a given motorcycle circuit
  to whichever output terminal is physically convenient, then use the
  app's Outputs screen to give that channel a name, pick how it switches,
  and tick the few role flags that carry real behaviour. Decide your layout
  on paper first, wire it, then configure it in the app to match — and label
  your wiring (tags, a diagram taped in the seat pocket) so a future you
  or a mechanic isn't guessing.
- **Bench-test before installing.** Power the board on the bench, pair it
  with the app, and exercise every output and input from the app before
  you connect it to the bike's actual loads. Confirm outputs switch, LEDs
  (LED1–LED12 mirror OUT1–OUT12 on the board itself) light up, and inputs
  register button presses.
- **Fuse every output for the load actually connected to it.** Match the
  fuse to the wire gauge and the load's actual current draw, not to the
  PROFET's absolute maximum — check the BTS7008-2EPA datasheet and this
  hardware revision's BOM (`hardware/releases/<rev>/bom/`) for the
  per-channel rating before assuming a number.
- **Keep a stock ignition kill switch and any stock immobilizer functional
  as a fallback** unless you fully understand what you're removing (see
  `DISCLAIMER.md`).

## Power

Board power comes in on the 4× M3 ring-terminal pads (main +12V and GND,
dual feed — see `hardware/PINOUT.md`'s "External connectors" section).
Operating range is 10–15V, LiFePO4-compatible. Connect to the bike's main
12V feed and a solid chassis/battery
ground, fused appropriately for the board plus everything it switches.

## Outputs (CN1, 12-pin terminal)

CN1 is a KF142V-5.08-12P terminal block: pin N = OUT*N* for N = 1…12
(`hardware/PINOUT.md`). Each output is a PROFET high-side switch — it
supplies switched +12V to the load; the load's other side returns to
chassis ground, same as any factory-wired 12V lighting/accessory circuit.

There is no fixed list of functions to pick from: a channel gets a
free-text name you choose ("Low Beam", "Heated Grips"), so name it after
whatever you actually wired to it.

**Behaviour** (Outputs screen) controls how a channel switches, independent
of what it's wired to:

- **toggle** — latching on/off. The right default for anything that isn't a
  turn signal or brake light.
- **momentary** — on only while its trigger is held (a held button, or a
  maintained switch like a brake lever).
- **blink** — full on/off flashing at a configurable rate. Turn signals,
  hazards, and anything you want blinking alongside them.
- **flasher** — a short attention-pulse burst on switch-on, then solid.
  Intended for the brake light.

Blink and flasher are always full on/off switching, never partial duty, so
they work with any lamp type including LED turn signals — no separate
flasher relay or load resistors needed. Brake flash patterns aren't legal
in every jurisdiction; check your local vehicle code before enabling one
(see the in-app note), and note it's off by default.

**PWM dimming** is separate from behaviour: set a channel's duty below 100%
and it dims whenever it's driven on. Off by default per channel — only turn
it on for loads you've confirmed tolerate PWM (LED lighting in particular
can flicker or misbehave under it). It never applies to blink or flasher.

**Role flags** are the only channel properties that carry safety logic, and
each is ticked explicitly rather than inferred from a name (see
[`docs/PROTOCOL.md`](PROTOCOL.md) §9 for the full field list):

- `essential` — never shed by the low-voltage cutoff. Tick it on anything
  that must not go dark or dead mid-ride: headlight, ignition, brake light,
  fuel pump.
- `is_ignition` — the immobilizer's target, and what the firmware reads to
  decide the bike is "running". At most one channel.
- `is_starter` — the starter output, which is special (see below). At most
  one channel.
- `is_brake` — the brake light, driven directly from the brake switch input.
- `indicator` (left/right) — a turn signal, which gets mutual exclusion and
  the auto-cancel timer. A channel that merely blinks along with the hazards
  (a DRL, say) is not an indicator — mark it a hazard member instead.

### Starter output — hardware button only, wired specially

The starter output is intentionally **not triggerable from the app** — only
the physical handlebar starter button (via CN2, below) can fire it, and
only when the immobilizer isn't `LOCKED` and the firmware doesn't believe
the engine is already running. Two independent checks decide that: if you've
assigned an output channel as the ignition (see below), that channel being
off always blocks the starter, with no configuration needed — an engine
can't be running with its ignition off. Voltage-based detection (reading
the charging line) is a second, **opt-in** layer you can turn on in
Diagnostics if you want the same protection to react automatically once the
engine is actually turning over; it's off by default because a booster pack
or jump box on the battery terminals looks identical to a running
alternator, and you don't want the starter refused on exactly the bike
you're trying to jump-start. Wire the starter output the way you'd wire any
starter-relay trigger circuit: it drives the starter relay coil, not the
starter motor directly. If your bike has (or you're adding) a neutral/clutch
safety interlock, wire that switch to one of the eight button inputs and
assign it as the `starter_interlock_input` on the Outputs screen — it's
optional but recommended.

### Brake light — priority over any flasher pattern

If you enable a brake-flasher attention pattern, the brake output is
still guaranteed solid-on for the entire time the brake input is asserted
— the flash pattern is only a prefix. Wire the brake switch input (front
and/or rear brake switch, whichever your bike already
has, or both wired to the same input) to one of the eight button inputs
and assign it as `brake_switch_input`.

## Inputs (CN2, 8-pin terminal, active-low)

CN2 is a KF142V-5.08-8P terminal block, wired in **reverse order** from
what you might expect — see `hardware/PINOUT.md`:

| CN2 pin | Signal |
|---|---|
| 1 | BTN8 |
| 2 | BTN7 |
| 3 | BTN6 |
| 4 | BTN5 |
| 5 | BTN4 |
| 6 | BTN3 |
| 7 | BTN2 |
| 8 | BTN1 |

Each input is active-low (pulled up internally; a button/switch should
short the input to ground when pressed/closed — no external pull-up
needed). Assign each input's short-press/long-press/double-press action in
the app, and use the dedicated fields for the two inputs that have a fixed
special meaning: `starter_interlock_input` and `brake_switch_input`
(Outputs screen, both optional). The button cheat-code (immobilizer fallback
unlock, see `docs/PROTOCOL.md` §11) is entered as a sequence of these same
handlebar button presses — decide your cheat-code layout with your final
button wiring in mind.

## Phone-as-key and the immobilizer

Nothing extra to wire for phone-as-key — it's BLE, not a physical
connection. The immobilizer cannot be enabled until you've configured at
least one non-phone way in, so you cannot wire yourself out of the bike:
either the button cheat-code (entered on whichever inputs you wired to CN2)
or a traditional ignition-switch input. That switch uses one of the eight
inputs the same way as the starter interlock/brake switch above. Whichever
you configure stays available even with phone-as-key enabled, and you can
set up both.

## After wiring: verify before riding

Work through [`docs/HARDWARE_TESTING.md`](HARDWARE_TESTING.md)'s bench
checklist — with the board still on the bench if possible, then again
once installed but before starting the engine, then a short stationary
test with the engine running (starter interlock, charging-voltage
detection) before an actual ride.

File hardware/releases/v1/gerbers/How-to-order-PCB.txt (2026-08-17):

How to Order PCB

Please refer to:
https://prodocs.easyeda.com/en/pcb/order-order-pcb/index.html

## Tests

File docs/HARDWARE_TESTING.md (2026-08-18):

# Hardware bench validation checklist

**Status: worked through on v1 hardware.** This is a per-release procedure,
not a one-time bring-up: run it again for every hardware revision and every
firmware release, since it is the only layer that covers real GPIO, real
current sensing, and real BLE. Check items off as you go; keep a copy per
revision/release (see the sign-off section at the bottom).

## Relationship to the software test pyramid

[`docs/TESTING.md`](TESTING.md) covers what's already proven without any
board: the portable core against synthetic time (`ctest`), the full wire
protocol against a real spawned simulator (the Node itest suite), and
QEMU boot validation of the real cross-compiled binary. Read that doc's
own caveats before assuming this checklist is redundant with any of it:

- QEMU **cannot** validate BLE (no radio controller emulation) — pairing,
  bonding, auth, and anything over the air is bench-only.
- The simulator's `engine_running`/battery/current values are injected
  directly over a debug channel, so no automated test exercises real ADC
  readings, real PROFET current sense, or the real voltage dividers.
  Calibration (`DIAG_SET_CALIB`) is meaningless until it has been done
  against a given board's actual analog front end.
- Timing (watchdog restore budget, debounce, BLE reconnect) is only ever
  measured by the automated layers against synthetic time or a desktop
  OS's wall clock, never the real MCU's timers under real load.

This checklist is where all of that gets proven. Don't read a clean bench
run as re-validating logic already covered by `docs/TESTING.md` — it isn't;
it's validating that the logic still holds once real silicon, real analog
signals, and real radio are involved.

## Before you start

- Flash the board per [`docs/FLASHING.md`](FLASHING.md) and confirm boot
  log output over `idf.py monitor` before doing anything else below.
- Nothing in this checklist should be run with the board wired into an
  actual motorcycle — bench power and bench loads only, until the very
  last section.
- Have a way to inject a variable 10–15V supply (a bench PSU) for the
  battery/voltage-threshold tests, and spare bulbs/LEDs/relays to use as
  test loads on the outputs (see [`docs/WIRING.md`](WIRING.md)).

## 1. Power-up

- [ ] Board powers up from bench 12V within the documented 10–15V range
      with no visible damage, smoke, or excessive heat from any component.
- [ ] Quiescent/idle current at rest is in a sane range; re-measure
      specifically in parked/advertising mode against the <2mA average
      target (`CONTRIBUTING.md` safety requirement #7) — this is a real
      current-clamp measurement, not something any simulator run can tell
      you. See §1.1 for the parked-power procedure.
- [ ] 3V3 rail present and stable (LED13 power indicator, per
      `hardware/PINOUT.md`).

### 1.1 Parked power (mc_power / light sleep)

`mc_power` steps the board down through ACTIVE (10ms tick) → IDLE (100ms,
light sleep) → PARKED (250ms, light sleep, ~1s BLE advertising). Reference
point: before any of this existed the board drew ~18mA continuously, and
~0mA with the ESP32-S3 held in reset — so essentially all of it is
MCU-side and in play.

- [ ] Baseline with EN held low is still ~0mA (confirms no new hardware
      draw crept in).
- [ ] Power up, leave the board completely alone with no phone connected,
      and watch the supply. Current should step down twice: once at
      `MC_POWER_DEFAULT_IDLE_AFTER_MS` (5s) and again at
      `MC_POWER_DEFAULT_PARKED_AFTER_MS` (60s). Record all three levels.
- [ ] **Wake works.** From PARKED, a single handlebar button press must
      wake the board and register as a press — no lost first press. This is
      the highest-risk item in this section: the GPIO interrupt notify and
      the light-sleep wake are separate mechanisms and their interaction is
      only settled on real silicon. If the first press is ever swallowed,
      the 250ms parked tick is the backstop and the notify path needs
      investigating (`input_hal_gpio_wake_init`).
- [ ] **Maintained switch held closed.** Ground an input assigned as the
      ignition switch and leave it grounded for several minutes, then open
      it again. The board must stay up. Regression check: the wake path uses
      a *level*-triggered interrupt (`gpio_wakeup_enable()` rejects edge
      modes and rewrites the pin's interrupt type to match), so a handler
      that does not mask its own pin re-enters forever and panics the
      interrupt watchdog within milliseconds — a maintained switch holds the
      pin low indefinitely, so this is certain rather than rare. Also power
      the board up with the switch *already* grounded, which is the same bug
      arriving during init.
- [ ] **Cheat-code entry from cold.** With the immobilizer engaged and the
      board parked, enter the full cheat-code at normal speed. It must
      unlock — nothing may be dropped mid-sequence. Layered unlock: this is
      the case where a bug locks a rider out of their own bike.
- [ ] **Phone reconnect from parked.** A paired phone must still connect
      and authenticate while the board is in PARKED (slower to be
      discovered is expected — roughly a second — failing to connect is
      not).
- [ ] **Never sleeps in use.** With any output on, the engine running, or
      an OTA in flight, current must stay at the ACTIVE level and blink /
      flasher timing must look unchanged by eye. A visible change in blink
      rate means a hold-awake gate is not doing its job.
- [ ] OTA transfer completes at the same speed as before.
- [ ] If the numbers come in higher than hoped, the first knob to try is
      `CONFIG_BT_CTRL_MAIN_XTAL_PU_DURING_LIGHT_SLEEP=n` in
      `sdkconfig.defaults` — but re-run the phone-reconnect and
      connection-stability items after changing it, since the main crystal
      is the BLE controller's low-power clock on this board.

## 2. Outputs (bench, one channel at a time)

For each of OUT1–OUT12:

- [ ] Commanding the channel on from the app switches a test load (bulb or
      LED + resistor) connected to that terminal, and the corresponding
      board LED (LED1–LED12) lights up.
- [ ] Commanding it off turns the load off, LED included.
- [ ] No other channel is affected (rules out a CN1 wiring/PROFET
      addressing mistake).
- [ ] PWM mode (if you enable it for a test channel): load visibly dims at
      partial duty and follows `pwm_duty_pct` changes from the app.
- [ ] Turn-signal / brake-flasher modes: real blink/pulse timing looks
      right by eye and roughly matches the configured period — the exact
      cycle-accurate timing is already unit-tested against synthetic time
      (`test_output.c`); this step is a sanity check that real GPIO/LEDC
      timing isn't wildly off, not a re-proof of the pattern logic.

## 3. Current sense / diagnostics

- [ ] `DIAG_GET` reports a plausible nonzero current for an actually-loaded
      channel, and ~0 for an unloaded one.
- [ ] `DIAG_SET_CALIB` round-trips and visibly changes subsequent reported
      current (confirms the wire op reaches real calibration storage, not
      just a no-op).
- [ ] Perform an actual gain/offset calibration against a known load and a
      multimeter on this board's IS line, and record the resulting
      `isGain`/`isOffsetMv`/`kilis`/`vbatGain`/`vbatOffsetMv` values for
      this specific board (`hardware/PINOUT.md`'s battery divider and
      current-sense notes both call out "calibrate per board" — this is
      that step, and it has to be redone for each individual board).
- [ ] Disconnect a loaded channel's bulb (open-load) and confirm a fault
      is reported within a reasonable time; re-connect and confirm it
      clears.
- [ ] `DIAG_LEARN` against a real energized channel sets a sane open-load
      threshold from the real measured current.

## 4. Battery voltage / low-voltage cutoff

Using a bench PSU in place of the battery:

- [ ] Reported `batteryMv` (STATUS) tracks the PSU voltage reasonably
      accurately after calibration (§3).
- [ ] Sweeping voltage down through the configured cutoff (default
      11.8V for LiFePO4, `CONTRIBUTING.md` safety requirement #7) engages
      the cutoff — non-essential outputs are suppressed, `lvCutoffActive`
      reports true.
- [ ] Sweeping back up past cutoff + hysteresis clears it.
- [ ] Confirm essential outputs (whichever channels you've ticked
      `essential`, plus the `is_ignition`/`is_brake` ones) are **never**
      suppressed by the cutoff, even at the lowest voltage tested.
- [ ] Voltage-based `engine_running` detection is **off by default**
      (`engineRunVoltageDetectionEnabled`, Diagnostics screen) — with it
      off, raising voltage past `engine_run_mv` must NOT make
      `engine_running` become true. This is the actual bug this toggle
      exists to fix: without it, a booster pack or this bench PSU alone
      would read as "engine running" and the starter test in §6 would find
      itself falsely refused.
- [ ] Turn the toggle on and confirm raising voltage into `engine_run_mv`
      now does make `engine_running` become true (visible via the
      diagnostics config / starter-inhibited behavior in §6), and that it
      clears again below `engine_run_mv - engine_run_hysteresis_mv`. Turn
      it back off afterward before continuing to §6, so the rest of the
      starter checklist reflects the real default a rider ships with.

## 5. Inputs

For each of BTN1–BTN8 (mind CN2's reversed pin order, `hardware/PINOUT.md`):

- [ ] A press registers (short-press action fires, or is visible via the
      GUI/app's live button state if you're driving straight from a
      handlebar switch bench mockup).
- [ ] Long-press and double-press are distinguishable at real human
      button-press speed (debounce/timing constants are unit-tested
      against synthetic time already — this checks real switch bounce on
      your actual switches doesn't break it).
- [ ] Wrong wiring/pin-order mistakes are ruled out: pressing what you
      think is BTN1 actually registers as BTN1, not BTN8.

## 6. Starter output + interlock

- [ ] Confirm the starter output **cannot** be switched on from the app at
      all (no wire op reaches it — `CONTRIBUTING.md` safety requirement #6)
      — this should already be structurally true, but confirm nothing on
      this board's assembly exposes it some other way (e.g. a debug jumper
      left populated).
- [ ] The physical starter button (wired to one of BTN1–BTN8) does fire the
      starter output when the engine isn't running and (if configured) the
      neutral/clutch interlock input is satisfied.
- [ ] With `engine_running` true (§4's voltage-based detection with the
      toggle explicitly enabled, or the actual engine running once
      installed), confirm the starter button no longer fires the output.
- [ ] **Ignition-off override.** Assign an output channel as `is_ignition`
      and leave voltage-based detection off (the shipping default). With
      the ignition channel OFF, confirm `engine_running` reads false no
      matter how high the bench PSU is driven — this is the fix for the
      booster-pack/jump-start false positive, and it must hold regardless
      of the voltage toggle. Turn the ignition channel ON and confirm the
      starter button now fires normally (with the engine genuinely not
      running).
- [ ] With a neutral/clutch interlock input configured and open/unsatisfied,
      confirm the starter button is inhibited.

## 7. BLE pairing, bonding, auth

Real radio — QEMU cannot validate any of this:

- [ ] Board advertises as `MOTO-CTRL` and is discoverable from the app.
- [ ] First-time pairing (trust-on-first-use enrollment) succeeds and the
      session authenticates.
- [ ] Reconnecting after a normal disconnect re-authenticates without
      re-enrolling.
- [ ] Reasonable range/RSSI behavior — confirm the connection survives at
      a realistic on-bike phone-to-board distance, and note where it starts
      to degrade.
- [ ] Enroll a second phone, confirm both can authenticate independently,
      revoke one, confirm the revoked one can no longer authenticate.
- [ ] An unauthenticated write (if you can script one, or via the sim GUI's
      equivalent unauth test pattern) is rejected.

### 7.1 Background reconnect (`src/ble/BoardSession.ts`)

The point of this feature: walk up to the bike with a paired phone in your
pocket, screen off, app not open, and have it connect and unlock on its
own. Everything below has been typechecked, compiled, and unit-tested
(`src/__tests__/BoardSession.test.ts`) but **never exercised against a real
phone** — this is exactly the kind of thing that only proves itself across
a genuine suspend/kill/relaunch cycle on real hardware, not in a simulator
or an emulator.

- [ ] **App open, board comes into range** — pair normally, background the
      app (home button, don't force-quit), walk out of range and back in.
      Reconnects and re-authenticates on its own (watch for
      `BleWatchService`'s notification on Android; nothing user-visible to
      check on iOS beyond the app showing Dashboard when reopened).
- [ ] **App backgrounded (not killed), phone locked.** Same as above with
      the screen off the whole time. iOS: this is the case
      `bluetooth-central`/state restoration is *least* likely to have
      trouble with (app process is merely suspended, not terminated).
- [ ] **iOS: app fully terminated** (swiped away in the app switcher, not
      just backgrounded), then walk into range. This is the real test of
      `restoreStateIdentifier`/`restoreStateFunction`
      (`src/ble/bleManager.ts`) — iOS has to relaunch the app in the
      background for a BLE event with no user interaction at all. Confirm
      the phone actually authenticates (check the board's event log or the
      app, once reopened, for a fresh session) — don't take "nothing crashed"
      as success.
- [ ] **Android: app backgrounded, notification visible.** Confirm
      `BleWatchService`'s notification appears (watching → connecting →
      "Connected to `<name>`" as the state changes) and that swiping it away
      doesn't kill the service (it's `setOngoing(true)` — it shouldn't be
      dismissible while running at all; if it *can* be swiped away, that's a
      bug to fix, not expected behavior).
- [ ] **Android: app force-stopped from Settings, or killed by the OS under
      memory pressure.** `START_STICKY` should get the service (and the
      process) recreated, but confirm — this is a real edge Android permits
      OEM battery-optimization features to break in ways this project can't
      control for (see the manual "disable battery optimization for this
      app" step some OEMs require, worth documenting in `docs/WIRING.md` or
      `docs/FAQ.md` if you find your device needs it).
- [ ] **Explicit Disconnect actually disconnects.** From Settings, tap
      Disconnect, confirm the board drops (BLE disconnects, and on Android
      `BleWatchService`'s notification disappears) and does **not**
      silently reconnect on its own afterward — walk away and back into
      range and confirm it stays disconnected until you reopen the app.
- [ ] **Auth failure retry timing.** Revoke this phone's key from another
      paired phone while this one is connected, confirm it gets kicked and
      then retries reconnecting on a visibly slower cadence than a plain
      out-of-range retry (30s vs 5s, `src/ble/BoardSession.ts`'s
      `AUTH_ERROR_RETRY_MS`/`CONNECT_RETRY_MS`) rather than hammering the
      radio.
- [ ] **Multiple boards.** If you own more than one, confirm pairing a
      second board (PairingScreen's manual tap flow) supersedes watching for
      the first rather than trying to watch both — this project's phone-as-key
      model is one phone, one board at a time, `saveLastDevice()` overwrites.

## 8. Immobilizer

With the immobilizer enabled and a cheat-code set:

- [ ] Phone-as-key auto-unlock on a fresh authentication actually releases
      a `LOCKED` bike.
- [ ] The button cheat-code unlocks it with no phone involved.
- [ ] Wrong-code lockout/backoff behaves as expected at real human button
      speed, and phone/ignition-switch unlock still work throughout the
      backoff (only the cheat-code itself is gated).
- [ ] Locking is refused while `engine_running` is true or the ignition
      output is live, on real hardware (not just the sim's injected
      state).
- [ ] Ownership transfer wipes keys and disables the immobilizer as
      expected.

## 9. Physical factory reset

> The "flag if this doesn't trigger at all" item that used to sit here was
> right, and it was confirmed by inspection rather than on the bench: the
> old `factory_reset_check()` sampled GPIO0 once, a few hundred ms into
> `app_main()`, and holding BOOT through reset enters UART download mode so
> the firmware never runs. There was no reachable gesture. It is now a
> 5-second arming window watched on the app tick — see
> `firmware/main/factory_reset.h`. **This has not been exercised on real
> hardware yet**; the items below are the first real test of it.

- [ ] Power the board up normally, **without** BOOT held. Within 5 seconds,
      press and hold BOOT for the full 10 seconds. Confirm the distinct
      all-outputs-blink pattern, that the board reboots itself, and that
      bonds and config were actually wiped (re-pairing required, config
      back to defaults).
- [ ] Releasing BOOT before 10 seconds cancels it with no effect. Pressing
      again while the 5-second window is still open still works.
- [ ] Waiting out the 5-second window and *then* holding BOOT for 10s does
      **nothing** — this is what stops a stuck button wiping a bike's
      config mid-ride. Confirm it stays inert for the rest of the run.
- [ ] Board calibration survives the reset (it describes the board, not the
      owner — see `nvs_calib_hal.h`).
- [ ] The confirmation blink does not trip the task watchdog: the pattern
      takes ~1.4s on the watchdog-monitored app task and feeds it between
      cycles. A reboot into a panic here is a bug, not a pass.

## 10. Watchdog / reboot / restore timing

- [ ] Force a reboot (power-cycle or watchdog trip) while outputs are on
      and confirm they're restored from persisted state. Measure the
      actual time to restore and confirm it's under the 250ms budget
      (`CONTRIBUTING.md` safety requirement #1) — on real hardware, not
      simulated ticks.
- [ ] Confirm the two strapping-pin outputs (GPIO3/GPIO46 → PROFET
      IN6/DEN3, `hardware/PINOUT.md`) come up correctly and don't glitch
      the corresponding channel during boot — this is the one pin-handling
      detail `hardware/PINOUT.md` explicitly calls out as needing real
      hardware to confirm, not just review.
- [ ] Corrupt/blank NVS on a **spare** or freshly-erased board and confirm
      safe fallback to defaults rather than a boot loop or crash (the sim
      proves the logic; this confirms real NVS behaves the same way).

## 11. OTA (real hardware, both directions)

- [ ] Flash an initial build over UART (`docs/FLASHING.md`), then perform a
      full OTA update over BLE from the app to a second signed build, and
      confirm the board reboots into the new image (check the reported
      firmware version in STATUS before/after).
- [ ] **Check whether the new image survives a second reboot.**
      `firmware/sdkconfig.defaults` enables
      `CONFIG_BOOTLOADER_APP_ROLLBACK_ENABLE`, but nothing in
      `firmware/main/` currently calls
      `esp_ota_mark_app_valid_cancel_rollback()` (or equivalent) to confirm
      the new image to the bootloader. If that's still true when you run
      this test, expect the bootloader to roll back to the previous image
      on the *second* reboot after an OTA update, even though the update
      itself reported success — that would be a real firmware gap to fix,
      not a wiring or bench-procedure problem. Confirm which behavior you
      actually see and record it here.
- [ ] Attempt an OTA update while `engine_running` is true (enable
      voltage-based detection for this check, per §4, or have the actual
      engine running with ignition on — off-by-default detection alone
      will not produce this state) or battery below the low-voltage
      cutoff, and confirm it's refused (`docs/PROTOCOL.md` §10.3) rather
      than silently proceeding.
- [ ] Confirm the currently-running image keeps the bike fully operable
      (outputs, immobilizer) throughout an entire OTA transfer, right up
      until the explicit reboot step.

## 12. Full install (last, on an actual motorcycle)

Only after everything above passes on the bench:

- [ ] Wire per [`docs/WIRING.md`](WIRING.md), fused per your bike's actual
      loads.
- [ ] With the engine off, re-verify every output/input/immobilizer
      behavior from §§2, 5, 8 now that they're on real vehicle circuits,
      not bench loads.
- [ ] Decide, and record here, whether this board ships with voltage-based
      `engine_running` detection on or off (default: off). If on: start
      the engine and confirm charging voltage is correctly detected as
      `engine_running` (§4/§6) and the starter is inhibited while running.
      If off: confirm instead that turning the ignition off still
      immediately inhibits the starter (the unconditional override, §6) —
      this is the only automatic protection active with detection off, and
      it depends entirely on an `is_ignition` channel actually being
      assigned and wired.
- [ ] A short stationary test (engine running, stand or center stand) for
      lighting/signal/brake-light behavior before an actual ride.
- [ ] Re-run the safety-critical subset (lights, brake light, starter
      interlock — `DISCLAIMER.md`) after every subsequent firmware update,
      on the bench, before riding again.

## Sign-off

| Field | Value |
|---|---|
| Hardware revision | (`hardware/PINOUT.md`'s revision, e.g. v1) |
| Firmware version | |
| Tester | |
| Date | |
| Result | pass / fail / partial (list open items) |
| Notes | |

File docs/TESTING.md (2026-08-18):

# MOTO-CTRL Testing & Pre-Hardware Validation

This document describes how MOTO-CTRL is tested before a physical board
exists, and how to keep testing it once one does. It's the companion to
[`docs/PROTOCOL.md`](PROTOCOL.md) (the real wire protocol). If code and
this document ever disagree, that's a bug — please report it.

The pre-hardware validation harness (sim debug GUI, QEMU boot validation)
lets the app, the lock/immobilizer system, and diagnostics (current-sense,
faults, engine-running/low-voltage cutoff) all be developed and tested with
no board on the desk. Injected faults drive the real diagnostics logic, not
a canned fault mask — see §3.1.

## 1. The test pyramid

| Layer | What it runs | What it validates | What it can't validate |
|---|---|---|---|
| Host unit tests (`ctest`, `firmware/sim/tests/`) | Portable core (`mc_*`) compiled for the host | State machines, protocol framing, crypto, config serialization — in isolation | Anything ESP-IDF-specific, timing on real hardware, BLE |
| Node integration tests (`firmware/sim/itest/`) | The sim binary + a real WebSocket client | Full protocol round-trips, cross-language Ed25519 (JS signs, C verifies) | ESP-IDF/BLE specifics |
| **Sim debug GUI** (`firmware/sim/gui/`) | The sim binary + a browser | Everything above, interactively, plus fault injection (§3) and multi-step scenarios (§4) | ESP-IDF/BLE specifics |
| **QEMU boot validation** (§5) | The real cross-compiled firmware binary, emulated | Boot sequence, NVS load, config/output restore, watchdog init — on the *actual target code*, when it boots at all (see §5's CI note) | **BLE/NimBLE radio behavior** — QEMU's Xtensa target has no BLE controller emulation |
| Bench hardware (`docs/HARDWARE_TESTING.md`) | Real board | Everything, including BLE, real GPIO, real current sensing | — |

No layer above the bottom one is a substitute for bench validation before
anything ships. The harness's payoff is that the app and the lock system
can be built and iterated on entirely against the sim, with a GUI good
enough to drive by hand and a scenario format good enough to replay a
specific bug by machine.

## 2. Running the sim + GUI locally

```sh
cd firmware/sim
cmake -S . -B build && cmake --build build
./build/moto_ctrl_sim 8010          # ws://127.0.0.1:8010
```

Then open `firmware/sim/gui/index.html` directly in a browser (no server, no
build step — it's static files; a `file://` URL works, since the page only
opens a WebSocket to the address you type, no other network access). Click
**Connect**. The default URL matches the sim's default port.

The GUI is a single static page (`index.html` + `app.js` + `style.css`) plus
a vendored copy of TweetNaCl.js for Ed25519 (`gui/vendor/`, see
`gui/vendor/README.md` — public domain, no CDN, no build step, consistent
with the project's no-cloud rule applying to dev tools too).

## 3. The sim-only debug channel

The GUI needs to do things no real client ever could: fake a battery
voltage, fake per-channel current, force a disconnect or a reboot. These go
over **`SIM_CH_DEBUG`** (byte `0x7F`), defined in
`firmware/sim/src/sim_protocol.h` — deliberately a *separate* header from
`mc_protocol.h`, so this never leaks into the real protocol third-party
clients implement against, and is never sent over real BLE. Framing matches
the real protocol: `[0x7F][opcode][payload]` on the same WebSocket
transport.

| Opcode | Direction | Payload | Effect |
|---|---|---|---|
| `SET_BATTERY_MV` (0x01) | → sim | `mv:u16le` | Injects the raw battery-sense reading; `mc_diag` calibrates and derives `battery_mv`, `engine_running`, and the low-voltage cutoff from it every tick (§3.1) |
| `SET_CHANNEL_FAULT` (0x02) | → sim | `channel:1 current_ma:u16le fault:1` | Injects a channel's raw current-sense reading; `mc_diag` calibrates and classifies the real fault from it (§3.1). The trailing `fault` byte is accepted for wire compatibility but **ignored** — forcing a fault independent of current would show a fault `mc_diag` itself never derived |
| `SET_ENGINE_RUNNING` (0x03) | → sim | `running:1` | Doesn't set the flag directly (mc_diag would overwrite it on the very next tick) — nudges the injected battery voltage to a value that makes the real derivation land on the requested state instead (§3.1) |
| `SET_INTERLOCK` (0x04) | → sim | `engaged:1` | Calls the real `mc_output_set_interlock_engaged()` |
| `BUTTON_STATE` (0x05) | → sim | `button:1 pressed:1` | Sets a virtual button's raw state, sampled by the sim's 10ms `mc_input_poll()` tick |
| `FORCE_DISCONNECT` (0x06) | → sim | — | Drops the WebSocket (simulated BLE disconnect) |
| `FORCE_REBOOT` (0x07) | → sim | — | Simulated MCU reset (§3.2), then drops the connection |
| `FORCE_NVS_CORRUPT` (0x08) | → sim | `target:1` (0=config,1=keystore,2=both,3=lock,4=calibration) | Flips bytes in the fake NVS blob; only observable on the next reboot |
| `GET_LOG` (0x09) | → sim | — | Replays the event log ring buffer (128 entries) |
| `GET_STATE` (0x0A) | → sim | — | Request a `STATE` snapshot |
| `RESET_FAULTS` (0x0B) | → sim | — | Resets injected battery/current back to defaults (mc_diag then re-derives fault/cutoff/engine_running from those on its own next tick); clears the interlock override too (does not touch lock state — that's not a "fault") |
| `ACK` (0x81) | ← sim | `req_op:1 ok:1` | Acknowledges a setter |
| `LOG_ENTRY` (0x90) | ← sim | `t_ms:u32le text_len:1 text` | One event, pushed live and on `GET_LOG` replay |
| `STATE` (0x91) | ← sim | `battery_mv:u16le running:1 interlock:1` then 12×`[current_ma:u16le fault:1]` then `lock_state:1 cheatcode_backoff:1` | `battery_mv`, `running`, `current_ma`, and `fault` are the **real `mc_diag`-computed values** (round-tripped through its calibration and threshold logic), not raw injected numbers — the same values `STATUS` reports over the real protocol, never out of sync with it |

### Lock/immobilizer note: no new debug opcodes

The lock/immobilizer system needed **no additions to `SIM_CH_DEBUG`** beyond
the `STATE` snapshot fields and the `FORCE_NVS_CORRUPT` lock target above.
The reason: every lock-affecting input the GUI needs to drive was already
covered —

- **Phone-as-key** and **cheat-code entry** go over the *real* protocol
  (`docs/PROTOCOL.md` §11's new COMMAND-channel opcodes), driven by the
  GUI's existing Auth panel and virtual buttons — not the debug channel at
  all.
- **Ignition-switch mode** reuses one of the 8 existing virtual buttons
  (`mc_lock_config_t.ignition_switch_input` is an input index, exactly like
  `starter_interlock_input`) — assign it via `MC_OP_LOCK_SET_CONFIG`, then
  hold that virtual button (mousedown) to simulate the switch being ON. A
  held virtual button already IS a maintained switch's debounced level; no
  separate simulated signal was needed.
- **Engine-running** was already simulated (`SET_ENGINE_RUNNING`) and
  mc_lock's parked/lock guards consume the same flag starter protection
  already used.

### Diagnostics note: no new debug opcodes

Diagnostics needed **no additions to `SIM_CH_DEBUG`** either — only a
semantic change to two existing opcodes (`SET_CHANNEL_FAULT`,
`SET_ENGINE_RUNNING`, both documented in the table above) and one new
`FORCE_NVS_CORRUPT` target (`4` = calibration blob). The reasons:

- **Current-sense.** `SET_CHANNEL_FAULT`'s `current_ma` field already
  existed as a pure display value; diagnostics wires it into `mc_diag`'s
  real HAL as the raw reading, so the same injection point now feeds real
  calibration + threshold classification instead of a hand-picked fault
  enum.
- **Battery / engine-running / low-voltage cutoff.** `SET_BATTERY_MV`
  already existed too; `mc_diag` derives everything else from it every
  tick. `SET_ENGINE_RUNNING` survives only as sugar that nudges the battery
  voltage to a value producing the requested state — see the table above.
- **Calibration** has no debug op at all: it's exercised through the
  **real** protocol (`DIAG_GET_CALIB`/`DIAG_SET_CALIB`, `docs/PROTOCOL.md`
  §12), same as lock config uses real ops rather than debug ones.

### Flashers/PWM note: no new debug opcodes

Flashers/PWM needed **no additions to `SIM_CH_DEBUG`** at all — every input
is already reachable over the *real* protocol: `SET_OUTPUT` and
`HAZARD_PRESS` (`docs/PROTOCOL.md` §13) for turn/hazard control, the config
JSON for mode/duty/timing/`brake_switch_input`, and the existing virtual
buttons + `mc_input_button_level()` for the brake-switch input itself (same
mechanism the ignition-switch input already uses, per the note above).

The one new question this raised: how do tests avoid waiting out a real
30-second auto-cancel timer or a 700ms blink period against the sim's real
wall clock? **Not** a time-warp debug opcode — tests just write a short
test-specific value (e.g. `turn_auto_cancel_ms: 300`) through the real
config-write path first, then sleep a real (short) interval and assert.
This is deliberately the same "use the real protocol to make the real
timing fast enough to test" approach the diagnostics `DIAG_SETTLE_MS`
sleeps already use, rather than adding sim-only time control that would
diverge from what a real client can actually do. Blink-phase-accurate
timing itself (exact on/off transitions at known millisecond offsets) is
not itest's job at all — that's `firmware/sim/tests/test_output.c`,
against synthetic time, deterministically.

### 3.1 Fault injection and the status wire

Early on, `mc_status_t.output_fault_mask` (`docs/PROTOCOL.md` §5) was a
reserved wire field that the **simulator** populated directly from
whatever fault enum the GUI injected — no ADC or threshold comparison
involved, only whatever the debug channel was told to report.

**Diagnostics changes this for real.** `mc_diag`
(`firmware/components/core/mc_diag.c`) now owns `output_fault_mask`,
`battery_mv`, `engine_running`, and the low-voltage cutoff — the same
compiled code that ships on-target, proven by the host `ctest` suite
(`test_diag.c`) and exercised end-to-end against a real spawned sim process
(`firmware/sim/itest/integration.test.mjs` and
`app/src/__tests__/sim.itest.test.js`). The sim's role shrinks to exactly
one thing: its
`mc_diag_hal_t` reads back `SET_BATTERY_MV`/`SET_CHANNEL_FAULT`'s injected
raw values instead of driving a real ADC — everything downstream of that
(calibration math, round-robin sampling, open-load/overcurrent
classification, engine_running/cutoff derivation with hysteresis) is the
real firmware logic running unmodified. The sim's *default* calibration is
deliberately an **identity mapping** (`firmware/sim/src/sim_nvs.h`'s doc
comment) so an injected reading shows up as the same number by default —
a test that explicitly calls `DIAG_SET_CALIB` still changes the reported
values, exactly like real hardware would.

**What's still not validated here**: real analog behavior — actual PROFET
`kILIS` accuracy, ADC offset/gain drift, DSEL/DEN mux settle timing, IS-line
crosstalk between channels, and the real charging-system voltage profile.
Those remain bench-only (`docs/HARDWARE_TESTING.md`); this layer proves the
portable logic is correct, not that the physical sense lines read true.

### 3.2 Simulated reboot / watchdog trip

`FORCE_REBOOT` reloads `mc_config_t` and `mc_keystore_t` from the sim's fake
NVS (`firmware/sim/src/sim_nvs.c`) through the **same** `mc_config_load()` /
`mc_keystore_deserialize()` code paths real firmware uses on a real reboot —
including the same fail-safe-to-defaults behavior on a corrupt or missing
blob (never abort — `CONTRIBUTING.md` safety requirement #1). It then calls
the real `mc_output_restore_from_config()`, timed against that same
requirement's **<250ms** restore budget, and logs the result (`PASS`/`FAIL`)
to the event log before
dropping the connection — a real reboot drops the BLE link too. Observed
restore times in testing are in the tens-to-low-hundreds of *microseconds*
(no flash access in the sim), so the budget is not a meaningful stress test
of the sim itself — it's meaningful once the equivalent QEMU/bench timing is
measured against real NVS flash latency.

The sim's debounced persistence (`mc_persist`, 2000ms, same as real
firmware) is **not** flushed before a forced reboot — a state change inside
the debounce window is genuinely lost, exactly like a real reboot would lose
it. This is a deliberate, realistic test case: toggle an output, immediately
force a reboot, and confirm the restored state reflects the *last flushed*
value, not the most recent command.

`FORCE_REBOOT` also reloads the lock config + `locked_flag` from the fake
NVS and re-runs `mc_lock_init()`, inside the same timed window — a
persisted `LOCKED` state restoring (with the ignition/starter immobilize
re-applied) is covered by the same 250ms budget check as the output
restore. Unlike config/keystore, lock/cheat-code changes are **never
debounced** (see `mc_lock.h`) — they persist immediately on every mutating
command, so there is no "lost inside the debounce window" case to test for
lock state specifically.

It also reloads board calibration from its own fake-NVS blob and re-runs
`mc_diag_init()` (also inside the timed window), resetting `mc_diag`'s
runtime state — current-sense history, `engine_running`, and cutoff status
— cleanly, same as a real reboot: current-sense history from before a
watchdog reset isn't meaningful to carry forward. Diagnostics *threshold*
config (open-load/overcurrent/cutoff/engine-run) rides `mc_config_t` and so
reloads as part of the same config reload the output restore already
depends on — no separate reload path needed for it. Calibration, like lock
state, persists **immediately** on `DIAG_SET_CALIB` rather than through the
debounced scheduler (a rare, deliberate installer/bench action, not a hot
path).

`mc_output_init()` (called fresh on every `FORCE_REBOOT`, same as a real
boot) zeroes the whole engine, including the per-channel
`turn_auto_cancel_deadline_ms[]`/`brake_burst_started_ms[]` runtime arrays —
a pending auto-cancel timer or an in-progress brake-flasher burst does not
survive a reboot, same "not meaningful to carry forward" doctrine as the
current-sense history above. Mode/duty/timing config rides
`mc_config_t.outputs` and so reloads through the existing config reload
path — no separate reload code needed for it, same as diagnostics
thresholds above.

## 4. Scenario recording & replay

The GUI's **Scenario recorder** panel records every action a human (or a
loaded scenario) triggers, with real relative timestamps, into a flat JSON
action list:

```json
{ "version": 1, "actions": [
  { "t": 0,    "name": "setBattery", "args": { "mv": 11500 } },
  { "t": 1200, "name": "buttonState", "args": { "button": 2, "pressed": true } },
  { "t": 1350, "name": "buttonState", "args": { "button": 2, "pressed": false } }
] }
```

`t` is milliseconds since recording started. `name` is a key into the GUI's
own action table (`ACTIONS` in `app.js` — the same table both live UI
buttons and scenario replay call through, so recording can never drift from
what replay does). Loading a scenario re-schedules every action at its
recorded offset via `setTimeout`, so e.g. "wrong cheat code 3 times while
battery is low" is captured once by hand and replayed byte-for-byte
thereafter, including timing (useful for combo/cheat-code window edge
cases, which are timing-sensitive by definition).

Scenario files are plain JSON, not committed anywhere by default — save the
ones worth keeping under a location of your choosing (e.g.
`firmware/sim/gui/scenarios/`, not yet created) as regression fixtures.
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

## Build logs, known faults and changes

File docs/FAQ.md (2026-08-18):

# FAQ

## What is MOTO-CTRL?

An open-source, programmable motorcycle control board — a 12-output,
8-input ESP32-S3 board that switches your bike's electrical loads
(lights, signals, ignition, starter relay, horn, accessories) over BLE,
with a phone-as-key immobilizer and a companion mobile app. It's meant as
an alternative to closed commercial products like the Motogadget m.Unit
Blue, but open: the design, firmware, and app are all published, and
assembled boards are sold Speeduino-style (open design, commercial boards
funded through the project itself).

## Where's the project up to right now?

See the **Status** line at the top of the repo's [`README.md`](../README.md).
This FAQ doesn't track that day-to-day.

## Is it safe? Is it certified?

No certification, and please read [`DISCLAIMER.md`](../DISCLAIMER.md) in
full before building, flashing, wiring, or riding with one. MOTO-CTRL has
not been through ISO 26262 functional-safety certification, DOT/ECE/UNECE
type approval, or CE/FCC/UKCA compliance testing. It's a hobbyist project.
The firmware follows a specific, non-negotiable set of safety requirements
(see `CONTRIBUTING.md` — ride-safe failure on disconnect/crash, immobilizer
state rules, layered unlock that can't lock you out, brake-light priority,
hardware-only starter, battery protection) that every change is held to,
but "we designed carefully" is not the same thing as "an independent body
certified this." You assume the risk — see the disclaimer for exactly what
that means.

## Can I buy an assembled board?

Only from the MOTO-CTRL project itself — see
[`LICENSE-NOTE.md`](../LICENSE-NOTE.md). Nobody else is authorized to sell
assembled boards, kits, or PCBs made from this design. Whether boards are
actually available yet depends on where hardware production is at — check
the README status line and `hardware/releases/` for what's been built.

## Can I build my own from the design files?

Yes — personal, noncommercial builds are explicitly permitted under both
licenses (code: PolyForm Noncommercial; hardware/docs: CC BY-NC-SA 4.0).
See [`LICENSE-NOTE.md`](../LICENSE-NOTE.md), [`docs/WIRING.md`](WIRING.md),
and [`docs/FLASHING.md`](FLASHING.md).

## Can I sell boards, kits, or a modified version?

No. Selling assembled boards, bare PCBs, kits, or enclosures made from
this design isn't permitted under either license, and modifying the
design doesn't change that — a fork is still noncommercial-restricted.
See [`LICENSE-NOTE.md`](../LICENSE-NOTE.md) for the full breakdown,
including how to ask about commercial licensing arrangements outside the
default terms.

## What phone / OS does the app need?

The app is bare React Native (not Expo), using `react-native-ble-plx` for
BLE. A physical device is required — BLE doesn't work on the iOS Simulator
or a stock Android emulator. No NFC/UWB "digital car key" style integration
is planned; phone-as-key here is BLE-proximity based.

Phone-as-key reconnects and unlocks on its own, without the app open —
you don't need to unlock your phone and open MOTO-CTRL to walk up and ride.
iOS uses CoreBluetooth state restoration (`restoreStateIdentifier` plus the
`bluetooth-central` background mode); Android runs a small foreground
service (a persistent low-priority notification while it's watching for or
connected to your board — that's expected, not a bug, and is what keeps
Android from freezing the app in the background). Neither has been verified
against real hardware yet — see `docs/HARDWARE_TESTING.md` §7's
background-reconnect checks. Regardless of how well it works on your phone, the
immobilizer still refuses to be enabled unless you've also configured a
non-phone unlock method (the button cheat-code or an ignition-switch input)
— see the dead-phone question above — so a background-reconnect bug can
never be the only thing standing between you and your bike.

## Does the app need an internet connection or an account?

No accounts, ever — full stop. The app talks to the board over BLE and to
nothing else, with exactly one narrow exception: checking for and
downloading firmware updates, which is two anonymous, unauthenticated
HTTPS GETs (a small version-manifest file, then the signed update itself)
to a single fixed URL — no login, no device ID, no analytics, and it never
blocks or degrades BLE pairing/control if it fails (see `CONTRIBUTING.md`'s
"No cloud, no telemetry, no accounts" section for the exact constraints).
BLE pairing, control, config, diagnostics, and the immobilizer all work
with the phone fully offline.

## What happens if my phone dies, I forget it, or BLE just isn't working?

You always have a non-phone way in. Before the immobilizer can be enabled
at all, you must configure at least one method that isn't the phone —
either the handlebar button cheat-code or a traditional ignition-switch
input wired to one of the inputs. Whichever you set stays available the
whole time; it is never disabled just because phone-as-key is also turned
on (layered unlock: you can't lock yourself out). Configure both if you
want two non-phone fallbacks.

## What if my phone is lost or stolen?

Revoke that phone's key from the app while authenticated with another
paired phone (or the cheat-code + a factory reset if you have no other
paired phone) — the device only ever stores public keys, so revoking one
is immediate and doesn't require the missing phone to be present. See
`docs/PROTOCOL.md` §6 for key management, and the ownership-transfer flow
if you're getting rid of the whole bike.

## What happens if the BLE connection drops or the app crashes?

Nothing changes on the board. Output state is never touched by a
disconnect, an app crash, or the phone simply not being there — that's the
project's first, hardest safety requirement. If the MCU itself reboots
(watchdog trip or brownout), outputs are restored from persisted state in
under 250ms.

## How do I fully factory-reset a board?

Hold the BOOT button for 10 seconds **while the board is already powered
on and running normally** (not during power-up — see
[`docs/FLASHING.md`](FLASHING.md)'s callout on why those two are
different) until you see the distinct all-outputs-blink confirmation
pattern. This wipes paired keys and configuration. Do this before
transferring the bike to a new owner, or if you're locked out with no
other recourse.

## How do firmware updates work?

Once a board is flashed and paired, routine updates go over BLE: the app
checks for a new signed release, downloads it, transfers it to the board,
and you choose when to apply it (the current firmware keeps running
throughout the transfer). See `docs/PROTOCOL.md` §10 for the wire protocol
and `tools/sign-firmware.py` for how releases get signed. The very first
flash of a bare board, or recovery if BLE itself isn't working, uses UART
instead — see [`docs/FLASHING.md`](FLASHING.md).

## Can I use a flashing turn-signal / brake-light attention pattern?

The board supports it (full on/off switching, so it works with any lamp
type including LED turn signals — no hyperflash workarounds needed), but
it's **off by default**, and flash patterns on brake lights aren't legal
in every jurisdiction — check your local vehicle code before enabling one.

## Why no USB? Why do I need a separate UART adapter to flash it?

Hardware simplicity — the board has a 3-pin UART header instead of a USB
port or auto-reset circuitry. See [`docs/FLASHING.md`](FLASHING.md) for
the manual BOOT/EN sequence this requires.

## Why no WiFi?

The ESP32-S3 module has WiFi hardware, but v1 firmware doesn't use it —
BLE 5 only. This keeps the board's radio surface and power budget smaller,
and there's no feature in this project that needs WiFi (the one network
exception — update checking — runs on the phone, not the board).

## Why can't the app trigger the starter directly?

Because that's exactly the kind of thing that shouldn't be remotely
triggerable — the starter output is only reachable from the physical
handlebar button, is inhibited whenever the firmware believes the engine
is already running, and supports an optional neutral/clutch interlock.
"Already running" is decided two ways: if you've assigned an ignition
output, that channel being off always blocks the starter — no setup
needed, since an engine can't run with its ignition off. Reading the
charging voltage is a second, opt-in layer you can turn on in Diagnostics
if you want the same protection while the engine is actually turning; it's
off by default because a booster pack or jump box looks identical to a
running alternator on that line, and refusing the starter on the bike
you're trying to jump-start would defeat the point.

## I found a bug. Where do I report it?

Use the issue templates (see [`CONTRIBUTING.md`](../CONTRIBUTING.md)). If
it's safety-relevant — outputs could end up in a wrong state, the
immobilizer's stopped/off requirement could be bypassed, or the unlock/auth
flow could be weakened — say so explicitly in the title; those get
priority.

## Can I contribute?

Yes — see [`CONTRIBUTING.md`](../CONTRIBUTING.md) for the ground rules
(the safety requirements there aren't up for debate in a PR), development
setup, and what a good PR looks like.

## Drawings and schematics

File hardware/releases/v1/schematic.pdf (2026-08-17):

IO12 20 IO13 21 IO14 22 IO21 23 IO47 24 IO48 25 IO45 26 IO0 27 IO35 28 IO36 29 IO37 30 IO38 31 IO39 32 IO40 33 IO41 34 IO42 35 RXD0 36 TXD0 37 IO2 38 IO1 39 GND 40 GND ⁴¹

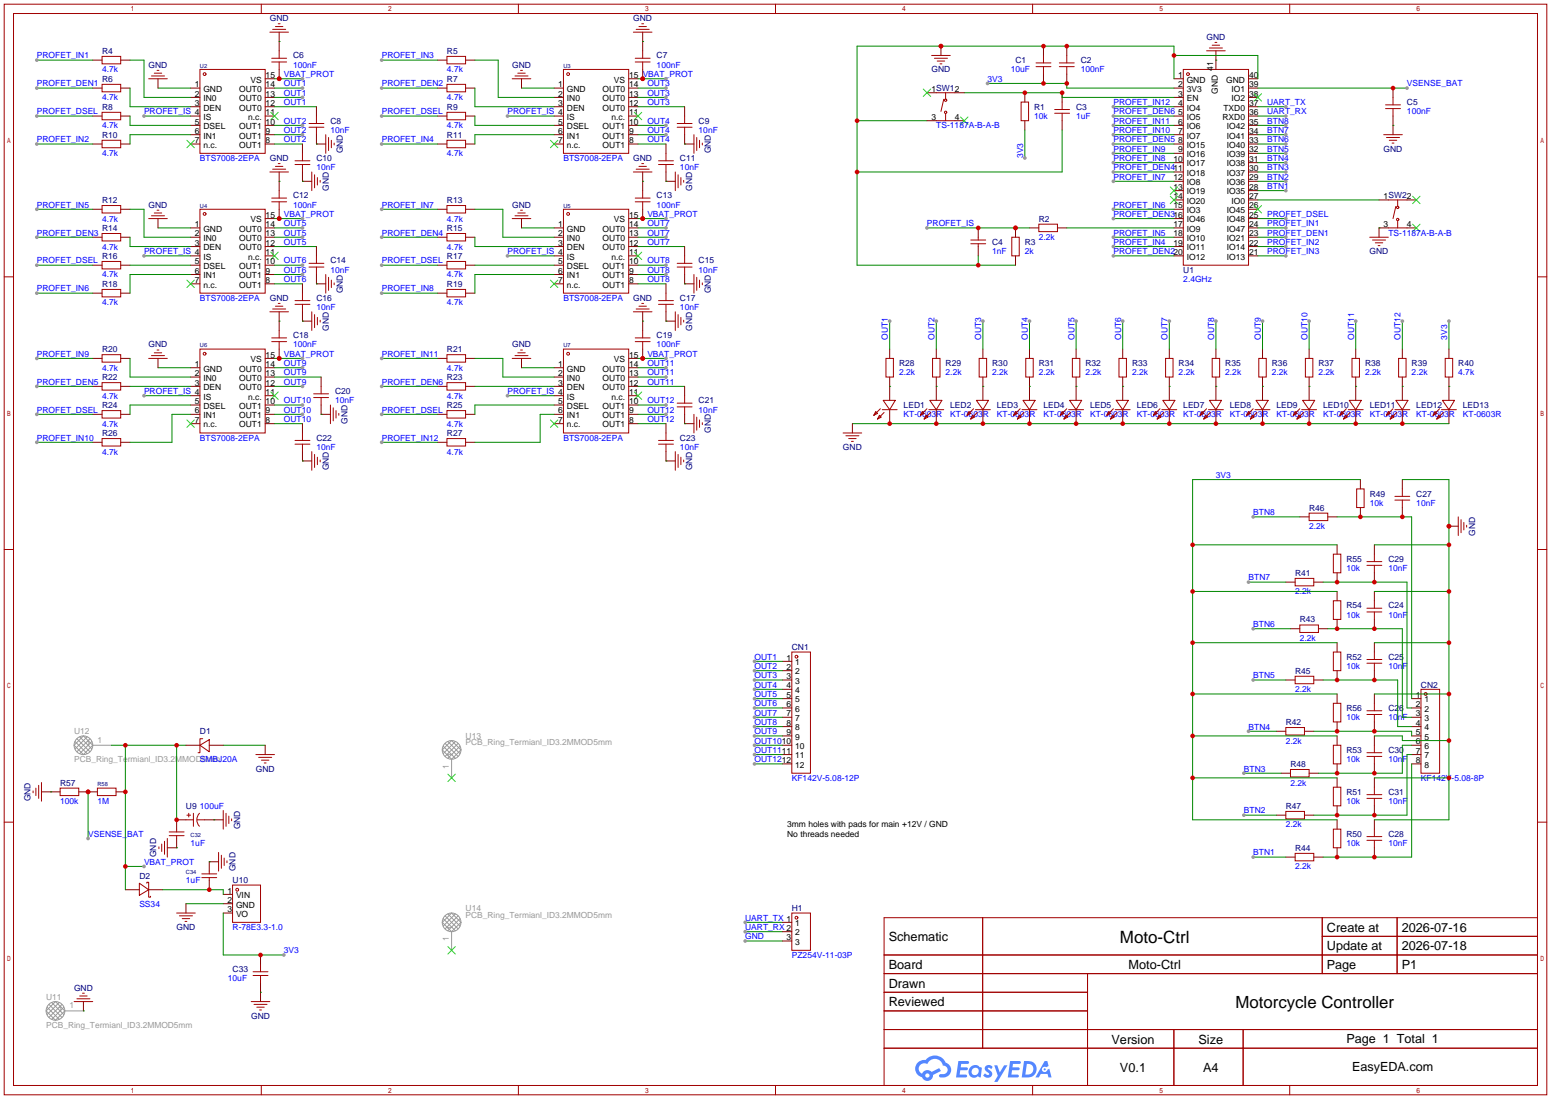
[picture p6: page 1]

3mm holes with pads for main +12V / GND
No threads needed

Schematic | Moto-Ctrl | Create at | 2026-07-16

Update at | 2026-07-18

Board | Moto-Ctrl | Page | P1
Drawn | | Motorcycle Controller
Reviewed

Version | Size | Page 1 Total 1
V0.1 | A4 | EasyEDA.com

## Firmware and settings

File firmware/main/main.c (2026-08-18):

#include <string.h>

#include "freertos/FreeRTOS.h"
#include "freertos/task.h"

#include "esp_log.h"
#include "esp_ota_ops.h"
#include "esp_sleep.h"
#include "esp_system.h"
#include "esp_task_wdt.h"
#include "esp_timer.h"
#include "nvs_flash.h"

#include "board_config.h"
#include "mc_config.h"
#include "mc_diag.h"
#include "mc_event_log.h"
#include "mc_input.h"
#include "mc_keystore.h"
#include "mc_lock.h"
#include "mc_ota.h"
#include "mc_ota_release_key.h"
#include "mc_output.h"
#include "mc_persist.h"
#include "mc_power.h"
#include "mc_session.h"
#include "mc_status.h"

#include "ble/ble_app.h"
#include "ble/gatt_svr.h"
#include "diag_hal.h"
#include "factory_reset.h"
#include "input_hal_gpio.h"
#include "nvs_calib_hal.h"
#include "nvs_config_hal.h"
#include "nvs_event_log_hal.h"
#include "nvs_keystore_hal.h"
#include "nvs_lock_hal.h"
#include "ota_hal.h"
#include "power_hal.h"
#include "output_hal_gpio.h"
#include "watchdog.h"

static const char *TAG = "moto_ctrl";

/* Shared device state the BLE sessions operate on. */
static mc_output_engine_t s_output;
static mc_config_t s_config;
static mc_keystore_t s_keystore;
static mc_lock_t s_lock;
static mc_diag_t s_diag;
static mc_ota_t s_ota;
static mc_event_log_t s_event_log;
static mc_app_t s_app;
static mc_input_engine_t s_input;
static mc_power_t s_power;

/* Debounced-write schedulers respecting NVS flash wear. Lock
 * state is NOT debounced here — see persist_lock_cb: lock/cheat-code
 * changes are rare and security-relevant enough to persist immediately. */
static mc_persist_scheduler_t s_persist_config;
static mc_persist_scheduler_t s_persist_keystore;

static uint32_t now_ms(void)
{
    return (uint32_t)(esp_timer_get_time() / 1000);
}

static void device_name_changed_cb(void *ctx)
{
    (void)ctx;
    ble_app_refresh_device_name();
}

static void persist_config_cb(void *ctx)
{
    (void)ctx;
    mc_persist_mark_dirty(&s_persist_config, now_ms());
}

static void persist_keystore_cb(void *ctx)
{
    (void)ctx;
    mc_persist_mark_dirty(&s_persist_keystore, now_ms());
}

/* Called synchronously (not debounced) right after any mutating lock op —
 * see mc_lock.h and mc_session.h's persist_lock hook doc comment. May run
 * on the NimBLE host task (a BLE-triggered lock command) rather than
 * app_task; app_task's own loop also flushes s_lock.dirty for
 * tick-driven transitions (auto-lock, auto-unlock) that don't go through
 * a command handler at all. */
static void persist_lock_cb(void *ctx)
{
    (void)ctx;
    if (nvs_lock_save(&s_lock) == ESP_OK) {
        mc_lock_clear_dirty(&s_lock);
    }
}

/* MC_OP_DIAG_SET_CALIB persists immediately, like persist_lock_cb — a rare,
 * deliberate installer/bench action, not a hot path (mc_session.h). */
static void persist_diag_calib_cb(void *ctx)
{
    (void)ctx;
    nvs_calib_save(&s_diag.calib);
}

/* Appends one event log record. Platform (not mc_session, which
 * has no clock by design) supplies uptime_ms, same doctrine as
 * fill_status_cb()'s st->uptime_ms below. */
static void log_event_cb(void *app_ctx, uint8_t type, uint8_t arg0, uint8_t arg1)
{
    (void)app_ctx;
    mc_event_log_append(&s_event_log, (mc_event_type_t)type, arg0, arg1, now_ms());
}

/* mc_app_t.on_session_authed: fired once by mc_session.c exactly when a
 * session's challenge-response newly succeeds. Auto-unlocks (edge-
 * triggered, not polled — see mc_lock.h) if the bike is currently LOCKED
 * and the PHONE method is enabled; a no-op otherwise. May run on the
 * NimBLE host task, same as any other BLE-triggered lock mutation. */
static void on_session_authed_cb(void *ctx)
{
    (void)ctx;
    bool was_locked = (s_lock.state == MC_LOCK_ST_LOCKED);
    mc_lock_request_unlock(&s_lock, &s_output, now_ms());
    /* Only actually writes flash if the bike was really LOCKED and this
     * call released it (mc_lock_is_dirty()) — a no-op unlock attempt
     * (already unlocked, or PHONE method disabled) never marks dirty, so
     * routine "phone connects while riding" auth doesn't cost a write. */
    if (mc_lock_is_dirty(&s_lock)) {
        persist_lock_cb(NULL);
    }
    if (was_locked && s_lock.state != MC_LOCK_ST_LOCKED) {
        log_event_cb(NULL, MC_EVT_LOCK_RELEASED, MC_EVT_UNLOCK_PHONE_AUTO, 0);
    }
}

static void fill_status_cb(mc_status_t *st, void *ctx)
{
    (void)ctx;
    st->uptime_ms = now_ms();
    st->rssi_dbm = 0;    /* filled once per-connection RSSI is wired */
    /* lock_state + the backoff bit are filled by mc_session's build_status
     * directly from app->lock (same as output_state_mask from app->output);
     * battery_mv + output_fault_mask are filled the same way from app->diag
     * — not this platform callback's job. */
}

/* Does `list` bind to output channel `ch`, either directly (the reserved
 * 256+N range) or via a function id that currently resolves to it? */
static bool binding_targets_channel(const mc_action_list_t *list, uint8_t ch)
{
    for (uint8_t i = 0; i < list->count && i < MC_ACTION_LIST_MAX; i++) {
        mc_action_id_t a = list->actions[i];
        if (a >= MC_ACTION_OUTPUT_TOGGLE_BASE &&
            a - MC_ACTION_OUTPUT_TOGGLE_BASE == ch) {
            return true;
        }
        if (a == MC_ACTION_TURN_L_TOGGLE || a == MC_ACTION_TURN_R_TOGGLE) {
            mc_indicator_side_t side =
                (a == MC_ACTION_TURN_L_TOGGLE) ? MC_INDICATOR_LEFT : MC_INDICATOR_RIGHT;
            if (mc_output_find_indicator_channel(&s_config.outputs, side) == (int)ch) {
                return true;
            }
        }
    }
    return false;
}

/* True if channel `ch` is configured momentary — i.e. driven by button LEVEL
 * in momentary_tick() below, so the press-event path must leave it alone or a
 * single press would both hold it (level) and toggle it (event). */
static bool channel_is_momentary(uint8_t ch)
{
    return ch < MC_OUTPUT_COUNT &&
           s_config.outputs.channels[ch].behaviour == MC_OUT_BEHAVIOUR_MOMENTARY;
}

/* Drives every momentary channel from the level of whichever button's
 * short-press binding targets it: on while held, off on release. Same
 * pass-through pattern as brake_switch_input (mc_output.h), just generalised
 * to any channel. Several buttons may target one channel — any of them held
 * holds the output.
 *
 * Called every tick BEFORE the press-event queue is drained, so a release is
 * honoured promptly rather than a tick late. */
static void momentary_tick(uint32_t t)
{
    /* A momentary channel follows button LEVEL, so skipping the press-event
     * dispatch above isn't enough to keep it quiet while an app is capturing
     * a cheat-code — the hold itself would still drive it. Treating every
     * button as released also means a channel that was being held when
     * capture started goes off rather than latching on for the duration. */
    bool suppressed = gatt_svr_input_actions_suppressed();

    for (uint8_t ch = 0; ch < MC_OUTPUT_COUNT; ch++) {
        if (s_config.outputs.channels[ch].behaviour != MC_OUT_BEHAVIOUR_MOMENTARY) {
            continue;
        }
        /* A momentary output follows a HOLD, never a tap: a single/double
         * tap binds to toggle/blink instead, so waiting for the hold
         * threshold keeps a tap from blipping the output. */
        bool held = false;
        for (uint8_t b = 0; b < MC_INPUT_COUNT && !held && !suppressed; b++) {
            if (binding_targets_channel(&s_config.inputs.long_press_actions[b], ch) &&
                mc_input_hold_active(&s_input, b)) {
                held = true;
            }
        }
        /* ...or a chord that is still being held down. */
        for (uint8_t i = 0; i < s_config.inputs.combo_count && !held && !suppressed; i++) {
            if (s_config.inputs.combos[i].type == MC_COMBO_CHORD &&
                binding_targets_channel(&s_config.inputs.combos[i].actions, ch) &&
                mc_input_chord_held(&s_input, i)) {
                held = true;
            }
        }
        if (held != mc_output_get_state(&s_output, ch)) {
            /* MC_OUT_SRC_LOCAL: this is the hardware-button path, so a
             * momentary starter binding is permitted here where the app's
             * remote SET_OUTPUT stays blocked (starter protection). The interlock
             * and engine-running guards still apply inside mc_output_set(),
             * and a rejected "on" simply leaves the channel off. */
            mc_output_set(&s_output, ch, held, MC_OUT_SRC_LOCAL);
        }
    }
    (void)t;
}

/* Executes one action binding. Shared by short/long/double press and by the
 * generic combos[] matcher so every binding path enforces identical policy:
 * every output change goes through mc_output_set() with MC_OUT_SRC_LOCAL,
 * which is where the immobilizer, the starter remote/engine-running/interlock
 * guards (starter protection) and turn mutual exclusion actually live. Returns
 * true if `action` was recognised. */
static bool dispatch_action(mc_action_id_t action, uint32_t t)
{
    if (action == MC_ACTION_NONE) {
        return false;
    }

    /* Direct channel binding (mc_types.h): toggle output N. */
    if (action >= MC_ACTION_OUTPUT_TOGGLE_BASE &&
        action < MC_ACTION_OUTPUT_TOGGLE_BASE + MC_OUTPUT_COUNT) {
        uint8_t ch = (uint8_t)(action - MC_ACTION_OUTPUT_TOGGLE_BASE);
        /* momentary_tick() owns this channel — toggling it here too would
         * fight the level and leave it inverted. */
        if (channel_is_momentary(ch)) {
            return true;
        }
        mc_output_set(&s_output, ch, !mc_output_get_state(&s_output, ch), MC_OUT_SRC_LOCAL);
        return true;
    }

    /* Alternating pair (mc_types.h): step hi/lo, or two DRL colours. */
    if (action >= MC_ACTION_OUTPUT_ALTERNATE_BASE &&
        action < MC_ACTION_OUTPUT_ALTERNATE_BASE + MC_OUTPUT_COUNT) {
        uint8_t ch = (uint8_t)(action - MC_ACTION_OUTPUT_ALTERNATE_BASE);
        int8_t partner = s_config.outputs.channels[ch].alternate_channel;
        /* Same reason as the toggle branch: momentary_tick() drives these
         * from button level, and stepping the pair here too would fight it. */
        if (channel_is_momentary(ch) ||
            (partner >= 0 && partner < MC_OUTPUT_COUNT && channel_is_momentary((uint8_t)partner))) {
            return true;
        }
        mc_output_alternate_press(&s_output, ch, MC_OUT_SRC_LOCAL);
        return true;
    }

    switch (action) {
    case MC_ACTION_TURN_L_TOGGLE:
    case MC_ACTION_TURN_R_TOGGLE: {
        mc_indicator_side_t side =
            (action == MC_ACTION_TURN_L_TOGGLE) ? MC_INDICATOR_LEFT : MC_INDICATOR_RIGHT;
        int ch = mc_output_find_indicator_channel(&s_config.outputs, side);
        if (ch >= 0 && !channel_is_momentary((uint8_t)ch)) {
            mc_output_set(&s_output, (uint8_t)ch, !mc_output_get_state(&s_output, (uint8_t)ch),
                          MC_OUT_SRC_LOCAL);
        }
        return true;
    }
    case MC_ACTION_HAZARD_TOGGLE:
        mc_output_hazard_press(&s_output, t);
        return true;
    default:
        return false;
    }
}

/* Runs every action in a binding, in list order. One trigger may drive
 * several outputs (mc_types.h's mc_action_list_t). */
static void dispatch_action_list(const mc_action_list_t *list, uint32_t t)
{
    for (uint8_t i = 0; i < list->count && i < MC_ACTION_LIST_MAX; i++) {
        dispatch_action(list->actions[i], t);
    }
}

/* Picks the binding for a press type. All three arrays are persisted and
 * round-tripped through the CONFIG channel (docs/PROTOCOL.md); before this
 * existed only short_press_action was ever read, so long/double bindings
 * were silently accepted and ignored. */
static const mc_action_list_t *actions_for_press(uint8_t button, mc_press_event_type_t type)
{
    static const mc_action_list_t none = { .count = 0 };
    if (button >= MC_INPUT_COUNT) {
        return &none;
    }
    switch (type) {
    case MC_PRESS_SHORT:  return &s_config.inputs.short_press_actions[button];
    case MC_PRESS_LONG:   return &s_config.inputs.long_press_actions[button];
    case MC_PRESS_DOUBLE: return &s_config.inputs.double_press_actions[button];
    default:              return &none;
    }
}
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
void app_main(void)
{
    /* Must be first: GPIO3/GPIO46 strapping-pin safety before any GPIO use. */
    board_config_early_init();
    /* docs/TESTING.md: CI's QEMU boot job greps stdout for these
     * "MOTO-CTRL boot:" markers to confirm the actual cross-compiled binary
     * reaches each milestone on emulated hardware — QEMU doesn't emulate the
     * NimBLE radio, so the markers bracket that gap rather than assume it. */
    ESP_LOGI(TAG, "MOTO-CTRL boot: early_init done");

    ESP_LOGI(TAG, "MOTO-CTRL firmware %d.%d.%d — board: %s",
             MC_FW_VERSION_MAJOR, MC_FW_VERSION_MINOR, MC_FW_VERSION_PATCH, BOARD_CONFIG_NAME);

    output_hal_gpio_init();
    input_hal_gpio_init();
    diag_hal_init();

    esp_err_t nvs_err = nvs_flash_init();
    if (nvs_err == ESP_ERR_NVS_NO_FREE_PAGES || nvs_err == ESP_ERR_NVS_NEW_VERSION_FOUND) {
        ESP_ERROR_CHECK(nvs_flash_erase());
        nvs_err = nvs_flash_init();
    }
    ESP_ERROR_CHECK(nvs_err);
    ESP_LOGI(TAG, "MOTO-CTRL boot: NVS init done");

    /* layered unlock's physical factory reset. Only ARMS here — the watching
     * happens on the app tick, for a few seconds only (see factory_reset.h
     * for why a check at power-on could never actually be triggered by hand).
     * Adds no delay to boot, which ride-safe failure's <250ms output restore
     * budget would not tolerate.
     *
     * Only on a real power-on. The gesture is "apply power, then hold BOOT",
     * so arming it on a watchdog reboot, a brownout recovery or an OTA
     * restart would re-open the wipe window at moments the rider never asked
     * for — several times a ride, in the OTA case. */
    if (esp_reset_reason() == ESP_RST_POWERON) {
        factory_reset_init();
    } else {
        ESP_LOGI(TAG, "factory-reset window not armed (reset reason %d, not power-on)",
                 (int)esp_reset_reason());
    }

    /* Config + keystore: degrade to defaults/empty on any NVS failure rather
     * than aborting (ride-safe failure — never let an error path drop outputs). */
    mc_config_default(&s_config);
    if (nvs_config_hal_init() == ESP_OK) {
        mc_config_result_t r = mc_config_load(nvs_config_hal_get(), &s_config);
        if (r != MC_CONFIG_OK) {
            ESP_LOGE(TAG, "config load failed (%d); using defaults", r);
            mc_config_default(&s_config);
        }
    } else {
        ESP_LOGE(TAG, "config NVS unavailable; using defaults");
    }

    mc_keystore_init(&s_keystore);
    if (nvs_keystore_hal_init() == ESP_OK) {
        if (nvs_keystore_load(&s_keystore) != ESP_OK) {
            ESP_LOGW(TAG, "keystore load failed; starting with no enrolled keys");
        }
    } else {
        ESP_LOGE(TAG, "keystore NVS unavailable; no enrolled keys");
    }

    /* Safety-critical: restore outputs from persisted state ASAP after boot
     * (ride-safe failure, <250ms). */
    mc_output_init(&s_output, &s_config.outputs, output_hal_gpio_get());
    mc_output_restore_from_config(&s_output);
    ESP_LOGI(TAG, "outputs restored from persisted config");
    ESP_LOGI(TAG, "MOTO-CTRL boot: outputs restored");

    /* Lock state: degrade to disabled/unlocked on any NVS failure, same
     * doctrine as config/keystore above — never guess into an immobilized
     * boot. Must run after mc_output_restore_from_config() (mc_lock_init
     * reads whether ignition is currently live, per ride-safe failure's
     * ride-safe restore override) and before app_task starts. */
    mc_lock_config_t lock_cfg;
    bool locked_flag = false;
    mc_lock_config_default(&lock_cfg);
    if (nvs_lock_hal_init() == ESP_OK) {
        if (nvs_lock_load(&lock_cfg, &locked_flag) != ESP_OK) {
            ESP_LOGW(TAG, "lock state load failed; starting disabled/unlocked");
            mc_lock_config_default(&lock_cfg);
            locked_flag = false;
        }
    } else {
        ESP_LOGE(TAG, "lock NVS unavailable; immobilizer stays disabled");
    }
    mc_lock_init(&s_lock, &lock_cfg, locked_flag, &s_output, now_ms());
    if (mc_lock_is_dirty(&s_lock)) {
        /* The ride-safe boot override fired (see mc_lock_init) — persist
         * the corrected state immediately rather than waiting for the
         * first app_task tick. */
        if (nvs_lock_save(&s_lock) == ESP_OK) {
            mc_lock_clear_dirty(&s_lock);
        }
    }
    ESP_LOGI(TAG, "lock state restored (wire state %d)", (int)mc_lock_wire_state(&s_lock));
    ESP_LOGI(TAG, "MOTO-CTRL boot: lock state restored");

    /* Board calibration: degrade to nominal/uncalibrated defaults on any NVS
     * failure, same doctrine as config/keystore/lock above. Never security-
     * or ride-safety-critical by itself (mc_diag_tick's own hysteresis and
     * the battery_mv==0 "unknown, don't cut off" guard bound the worst case
     * of a bad calibration), so this degrades quietly rather than logging
     * at error level. Thresholds (mc_diag_config_t) come from s_config.
     * diagnostics, already loaded above as part of s_config. */
    mc_diag_calib_t diag_calib;
    mc_diag_calib_default(&diag_calib);
    if (nvs_calib_hal_init() == ESP_OK) {
        if (nvs_calib_load(&diag_calib) != ESP_OK) {
            ESP_LOGW(TAG, "calibration load failed; using nominal/uncalibrated defaults");
            mc_diag_calib_default(&diag_calib);
        }
    } else {
        ESP_LOGW(TAG, "calibration NVS unavailable; using nominal/uncalibrated defaults");
    }
    mc_diag_init(&s_diag, &s_config.diagnostics, &diag_calib, diag_hal_get());
    ESP_LOGI(TAG, "MOTO-CTRL boot: diagnostics engine ready");

    mc_input_init(&s_input, &s_config.inputs);
    ESP_LOGI(TAG, "MOTO-CTRL boot: input engine ready");

    /* OTA. ota_hal_init() starts the dedicated low-priority flash-
     * write task (ota_hal.c); mc_ota_init() itself does no I/O. */
    ota_hal_init();
    mc_ota_init(&s_ota, ota_hal_get(), MC_OTA_RELEASE_PUBKEY);
    ESP_LOGI(TAG, "MOTO-CTRL boot: OTA ready");

    /* Event log, on its own dedicated "evtlog" NVS partition —
     * degrades to an empty (but still functional in-RAM) log on any NVS
     * failure, same doctrine as config/keystore/lock/calib above; a broken
     * event log must never become a reason to fail boot or drop outputs. */
    if (nvs_event_log_hal_init() != ESP_OK) {
        ESP_LOGE(TAG, "event log NVS unavailable; history will not persist this boot");
    }
    mc_event_log_init(&s_event_log, nvs_event_log_hal_get());
    ESP_LOGI(TAG, "MOTO-CTRL boot: event log ready");

    mc_persist_init(&s_persist_config, 2000);
    mc_persist_init(&s_persist_keystore, 2000);

    s_app.output = &s_output;
    s_app.config = &s_config;
    s_app.keystore = &s_keystore;
    s_app.lock = &s_lock;
    s_app.diag = &s_diag;
    s_app.ota = &s_ota;
    s_app.event_log = &s_event_log;
    s_app.input = &s_input;
    s_app.fill_status = fill_status_cb;
    s_app.persist_config = persist_config_cb;
    s_app.on_device_name_changed = device_name_changed_cb;
    s_app.persist_keystore = persist_keystore_cb;
    s_app.persist_lock = persist_lock_cb;
    s_app.persist_diag_calib = persist_diag_calib_cb;
    s_app.on_session_authed = on_session_authed_cb;
    s_app.log_event = log_event_cb;
    s_app.app_ctx = NULL;

    mc_watchdog_init();
    ESP_LOGI(TAG, "MOTO-CTRL boot: watchdog init done");

    ESP_LOGI(TAG, "MOTO-CTRL boot: starting BLE stack");
    ble_app_start(&s_app);
    ESP_LOGI(TAG, "MOTO-CTRL boot: BLE stack started");

    /* Power policy last, so every gate it reads (outputs, lock, diag, OTA)
     * is already initialised and it never sees a half-built device. Both PM
     * locks start held, so the loop below runs at full rate until the policy
     * says otherwise. */
    mc_power_config_t power_cfg;
    mc_power_config_default(&power_cfg);
    mc_power_init(&s_power, &power_cfg, now_ms());
    power_hal_init();

    TaskHandle_t app_task_handle = NULL;
    xTaskCreate(app_task, "mc_app", 4096, NULL, 5, &app_task_handle);
    /* Buttons must be able to cut a parked tick short — see
     * input_hal_gpio_wake_init(). Registered after the task exists so the
     * ISR always has something to notify. */
    input_hal_gpio_wake_init(app_task_handle);
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

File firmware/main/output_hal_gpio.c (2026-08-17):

#include "output_hal_gpio.h"

#include "board_config.h"
#include "driver/gpio.h"
#include "driver/ledc.h"
#include "esp_log.h"

static const char *TAG = "output_hal_gpio";
static const gpio_num_t s_out_pins[BOARD_OUTPUT_COUNT] = BOARD_OUTPUT_IN_PINS;

void output_hal_gpio_init(void)
{
    uint64_t mask = 0;
    for (int i = 0; i < BOARD_OUTPUT_COUNT; i++) {
        mask |= (1ULL << s_out_pins[i]);
    }
    gpio_config_t io_conf = {
        .pin_bit_mask = mask,
        .mode = GPIO_MODE_OUTPUT,
        .pull_up_en = GPIO_PULLUP_DISABLE,
        .pull_down_en = GPIO_PULLDOWN_DISABLE,
        .intr_type = GPIO_INTR_DISABLE,
    };
    gpio_config(&io_conf);
}

/* --- PWM dimming, lazily attached.
 *
 * PWM dimming is opt-in per channel and off by default (the PWM/flasher
 * rule) — most boards will never call output_hal_gpio_set_duty()
 * at all, so this deliberately does NOT reconfigure every output pin onto
 * LEDC at init time (that would mean every channel, including the common
 * case of a plain digital load, goes through the LEDC peripheral instead of
 * the already-correct, already-tested plain GPIO path — more risk for no
 * benefit). Instead, a channel's pin is claimed onto LEDC only the first
 * time dimming is actually requested for it; a channel that's never used
 * PWM mode always takes the plain gpio_set_level() path below, including
 * every flasher-pattern channel (flashers are always full on/off, never
 * partial duty, so mc_output.c never calls set_duty() for one) — zero LEDC
 * overhead or risk for the common case.
 *
 * Once a channel HAS been attached to LEDC, though, the peripheral owns
 * that pin's signal — a later plain gpio_set_level() call would fight the
 * LEDC hardware rather than reliably override it. So output_hal_gpio_set()
 * below checks the same attachment map: once attached, even an ordinary
 * on/off (e.g. the channel's mode later reverts to plain ON, or it's
 * simply commanded off) is expressed as an LEDC duty of 0 or full-scale,
 * not a raw GPIO write.
 *
 * ESP32-S3's LEDC has 8 channels in LEDC_LOW_SPEED_MODE (its only speed
 * mode — LEDC_HIGH_SPEED_MODE doesn't exist on this target), so at most 8
 * of the 12 output channels can be dimmed concurrently; a 9th concurrent
 * request is refused (logged, falls back to plain digital-on) rather than
 * doing anything unsafe. In practice, dimming more than a handful of
 * channels (headlight, maybe an aux running light) on one bike is an
 * unlikely configuration.
 *
 * ~1kHz / 10-bit resolution: comfortably above any human-visible flicker
 * threshold. Not bench-validated against the BTS7008-2EPA's actual PWM
 * frequency tolerance or for EMI. */
#define OUTPUT_HAL_LEDC_TIMER LEDC_TIMER_0
#define OUTPUT_HAL_LEDC_FREQ_HZ 1000
#define OUTPUT_HAL_LEDC_RES LEDC_TIMER_10_BIT
#define OUTPUT_HAL_LEDC_DUTY_MAX ((1u << 10) - 1u) /* matches OUTPUT_HAL_LEDC_RES */
#define OUTPUT_HAL_LEDC_CHANNEL_COUNT 8

static bool s_ledc_timer_ready = false;
/* channel_slot[i] = the output channel currently occupying LEDC channel i,
 * or -1 if free. */
static int8_t s_ledc_channel_slot[OUTPUT_HAL_LEDC_CHANNEL_COUNT];
/* ledc_channel_for_output[c] = which LEDC channel output channel c is
 * attached to, or -1 if never attached (still plain GPIO). */
static int8_t s_ledc_channel_for_output[BOARD_OUTPUT_COUNT];
static bool s_ledc_maps_initialized = false;

static void ledc_maps_init_once(void)
{
    if (s_ledc_maps_initialized) {
        return;
    }
    for (int i = 0; i < OUTPUT_HAL_LEDC_CHANNEL_COUNT; i++) {
        s_ledc_channel_slot[i] = -1;
    }
    for (int i = 0; i < BOARD_OUTPUT_COUNT; i++) {
        s_ledc_channel_for_output[i] = -1;
    }
    s_ledc_maps_initialized = true;
}
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

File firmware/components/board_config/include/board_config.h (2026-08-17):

#pragma once

/*
 * board_config — the ONE place GPIO numbers are allowed to appear in
 * firmware. Generated from hardware/PINOUT.md (board "Integrated V2",
 * schematic 2026-07-18). If PINOUT.md changes for a new hardware revision,
 * regenerate this header from it — do not hand-edit pins in both places.
 *
 * Channels are 0-indexed here (channel 0 == OUT1 .. channel 11 == OUT12),
 * matching mc_output's 0-indexed channel numbering.
 */

#include <stdint.h>

#define BOARD_CONFIG_NAME "moto-ctrl-v2"

#define BOARD_OUTPUT_COUNT 12
#define BOARD_INPUT_COUNT 8

/* --- PROFET outputs: IN pin per channel (OUT1..OUT12), 0-indexed --- */
#define BOARD_OUTPUT_IN_PINS \
    { 47, 14, 13, 11, 10, 3, 8, 17, 16, 7, 6, 4 }

/* DEN pin per channel — each PROFET's DEN line is shared by its two
 * channels (U2 DEN1 for OUT1/OUT2, U3 DEN2 for OUT3/OUT4, etc). Only one
 * PROFET may have DEN high at a time (see PINOUT.md's diagnostics
 * readout procedure) — that round-robin sequencing is handled in mc_diag,
 * this table just records which DEN pin belongs to which channel. */
#define BOARD_OUTPUT_DEN_PINS \
    { 21, 21, 12, 12, 46, 46, 18, 18, 15, 15, 5, 5 }

#define BOARD_DSEL_PIN 48
#define BOARD_IS_ADC_GPIO 9 /* ADC1_CH8 */

/* --- Handlebar buttons BTN1..BTN8, 0-indexed, active-low at the pin --- */
#define BOARD_BUTTON_PINS \
    { 35, 36, 37, 38, 39, 40, 41, 42 }

/* --- Analog --- */
#define BOARD_VSENSE_BAT_ADC_GPIO 1 /* ADC1_CH0 */
#define BOARD_VSENSE_BAT_DIVIDER_RATIO 0.0909f /* 1MΩ/100kΩ, calibrate offset/gain per board */

/* --- System / programming --- */
#define BOARD_UART_TX_PIN 43
#define BOARD_UART_RX_PIN 44
#define BOARD_BOOT_PIN 0 /* SW2: also the runtime factory-reset button (hold at power-on) */

/* --- Reserved --- */
/* Reserved for a future NTC board-temp sensor / 5V rail monitor. Routed to
 * no net on rev v1, and no driver reads it yet — the pin number is defined
 * here so a future driver has one place to get it from. */
#define BOARD_SPARE_ADC_GPIO 2

/*
 * Strapping pins used as PROFET outputs: GPIO3 (OUT6 IN, U4 PROFET_IN6)
 * and GPIO46 (U4 PROFET_DEN3, shared by OUT5/OUT6). Verified safe on this
 * hardware (see PINOUT.md), but firmware must never enable internal
 * pullups on these two pins before boot completes, and must drive them
 * low during early init — do this before any other GPIO or peripheral
 * setup. See board_config_early_init() in board_config.c.
 */
#define BOARD_STRAP_PIN_OUT6_IN 3
#define BOARD_STRAP_PIN_U4_DEN 46

/* Drives the GPIO3/GPIO46 strapping pins low with no pullups, before any
 * other GPIO or peripheral init. Call this first thing in app_main(),
 * before mc_output_restore_from_config() or anything else touches GPIO. */
void board_config_early_init(void);

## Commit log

2026-07-26 First pass full stack
    [partitions.csv]
2026-08-16 ignition bug fixes, OTA updates
    [mc_lock.h]
2026-08-17 add hardware files
    [Drill_PTH_Through.DRL, Drill_PTH_Through_Via.DRL, Gerber_BoardOutlineLayer.GKO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]
2026-08-17 documentation cleanup
    [partitions.csv]
